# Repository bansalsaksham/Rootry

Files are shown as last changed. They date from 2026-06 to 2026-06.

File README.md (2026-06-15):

# Rootry (formerly SoilHawk) | Automatic Irrigation System

An evolving hardware IoT project focused on providing low-cost, high-efficiency, solar-powered precision irrigation for smallholder farms in India. What began as an award-winning science exhibition prototype has evolved into a field-tested product architecture achieving significant water conservation.

**Key Achievements:**
* 🏆 **Runner-up (2nd Worldwide):** UPenn EcoVenture Global Climate Venture Competition (2024)
Saksham Certificate_page-0001

* 🏆 **Winner:** CBSE National Science Exhibition (2019) & Regional Science Exhibition (2018-19)
* 🌟 **Government Recognition:** Recommended as *Jal Doot* by the Ministry of Jal Shakti

---

## 🚀 The Product Evolution

This project has undergone several architectural iterations, moving from a basic microcontroller logic proof-of-concept to a distributed ML concept, and finally to a robust, custom ESP32 IoT system.

### Phase 3: Rootry v2 (Current Architecture - 2024 to Present)
The current iteration focuses on productization, robustness, and real-world deployment constraints. Designed for areas with limited grid power and no smartphone access, keeping the unit cost under ₹4,000.

* **Verified Impact:** Field-tested across a 4-acre site, achieving a **30% reduction** in water usage (250 L/m² vs control of 360 L/m²).
* **Hardware Stack:** * Custom PCB designed in **KiCad**.
  * **MCU:** ESP32-S3 (Dual-core 240MHz) replacing the legacy Arduino architecture.
  * **Connectivity:** Hybrid Dual GSM (SIM800L via UART AT commands) + WiFi interface.
  * **Power:** 10W Solar Panel + 12V SLA Battery with PWM charge controller.
* **Firmware Improvements:**
  * Replaced all legacy `delay()` calls with non-blocking loops using `millis()`.
  * Implemented **Hysteresis Band Control**: Pump turns ON below 30% moisture and OFF above 50% to prevent rapid toggling.
  * **Adaptive Temperature Compensation:** Stop thresholds dynamically raise to 60% when ambient temperatures exceed 35°C (read via DHT22).
  * **Web Dashboard:** `ESPAsyncWebServer` integration for a real-time localized dashboard.

---

### Phase 2: SoilHawk (2023 - ImpactHack Sponsor Track Winner)
A conceptual expansion into a distributed, multi-node architecture utilizing both ground-based sensing and aerial diagnostic telemetry. This phase validated the integration of machine learning for targeted agricultural interventions.

Add your next level pages (1)

---

### Phase 1: The Foundation (2019 Prototype)
The genesis of the project. A standalone prototype built to demonstrate the core viability of automated soil moisture management to prevent soil degradation and conserve water. 

* **The Setup:** Arduino Uno, FC-28 Soil Moisture Sensor, DHT11 Temperature/Humidity Sensor, 16x2 LCD, 5V Relay for water pump actuation, and a basic GSM module.
* **Logic:** Basic linear logic. The system reads analog moisture thresholds. If the soil falls below `MAXDRYNESS 600`, the pump is triggered, and the GSM module dispatches an SMS alert ("Motor Start") to the farmer.
* **Validation:** Documented in a formal research paper analyzing the mathematical and environmental impact, endorsed by Dr. Sumeet Gill, Professor of Computer Science at MDU Rohtak.



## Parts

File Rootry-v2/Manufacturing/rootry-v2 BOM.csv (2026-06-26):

Id | Designator | Footprint | Quantity | Designation | Supplier and ref
1 | D3 | D_DO-41_SOD81_P10.16mm_Horizontal | 1 | 1N5817
2 | C9,C8,C4,C3,C5,C6 | C_Disc_D5.0mm_W2.5mm_P5.00mm | 6 | 100nF
3 | K1 | Relay_SPDT_Omron_G5V-1 | 1 | G5V-1-12VDC
4 | J5,J6 | TerminalBlock_MaiXu_MX126-5.0-02P_1x02_P5.00mm | 2 | Conn_01x02
5 | R9,R7 | R_Axial_DIN0207_L6.3mm_D2.5mm_P10.16mm_Horizontal | 2 | 4.7k
6 | U2 | SOT-223-3_TabPin2 | 1 | AMS1117-3.3
7 | J2-DHT22,J1-SOIL1 | PinHeader_1x03_P2.54mm_Vertical | 2 | Conn_01x03
8 | C10,C7 | CP_Radial_D10.0mm_P5.00mm | 2 | 1000uF
9 | C11 | CP_Radial_D6.3mm_P2.50mm | 1 | 100uF
10 | D2 | LED_D5.0mm | 1 | LED
11 | R1,R3,R5,R4 | R_Axial_DIN0207_L6.3mm_D2.5mm_P10.16mm_Horizontal | 4 | 10k
12 | Q1 | TO-92_Inline | 1 | BC547
13 | U1 | ESP32-S3-WROOM-1 | 1 | ESP32-S3-WROOM-1
14 | J4-SIM80L1,J3-LCD1 | PinHeader_1x04_P2.54mm_Vertical | 2 | Conn_01x04
15 | C1,C2 | CP_Radial_D5.0mm_P2.50mm | 2 | 10uF
16 | SW2 | SW_PUSH_6mm_H5mm | 1 | BOOT
17 | R6 | R_Axial_DIN0207_L6.3mm_D2.5mm_P10.16mm_Horizontal | 1 | 4.7K
18 | SW1 | SW_PUSH_6mm_H5mm | 1 | RESET
19 | R2 | R_Axial_DIN0207_L6.3mm_D2.5mm_P10.16mm_Horizontal | 1 | 1k
20 | D1 | D_DO-41_SOD81_P10.16mm_Horizontal | 1 | 1N4007
21 | R10 | R_Axial_DIN0207_L6.3mm_D2.5mm_P10.16mm_Horizontal | 1 | 220

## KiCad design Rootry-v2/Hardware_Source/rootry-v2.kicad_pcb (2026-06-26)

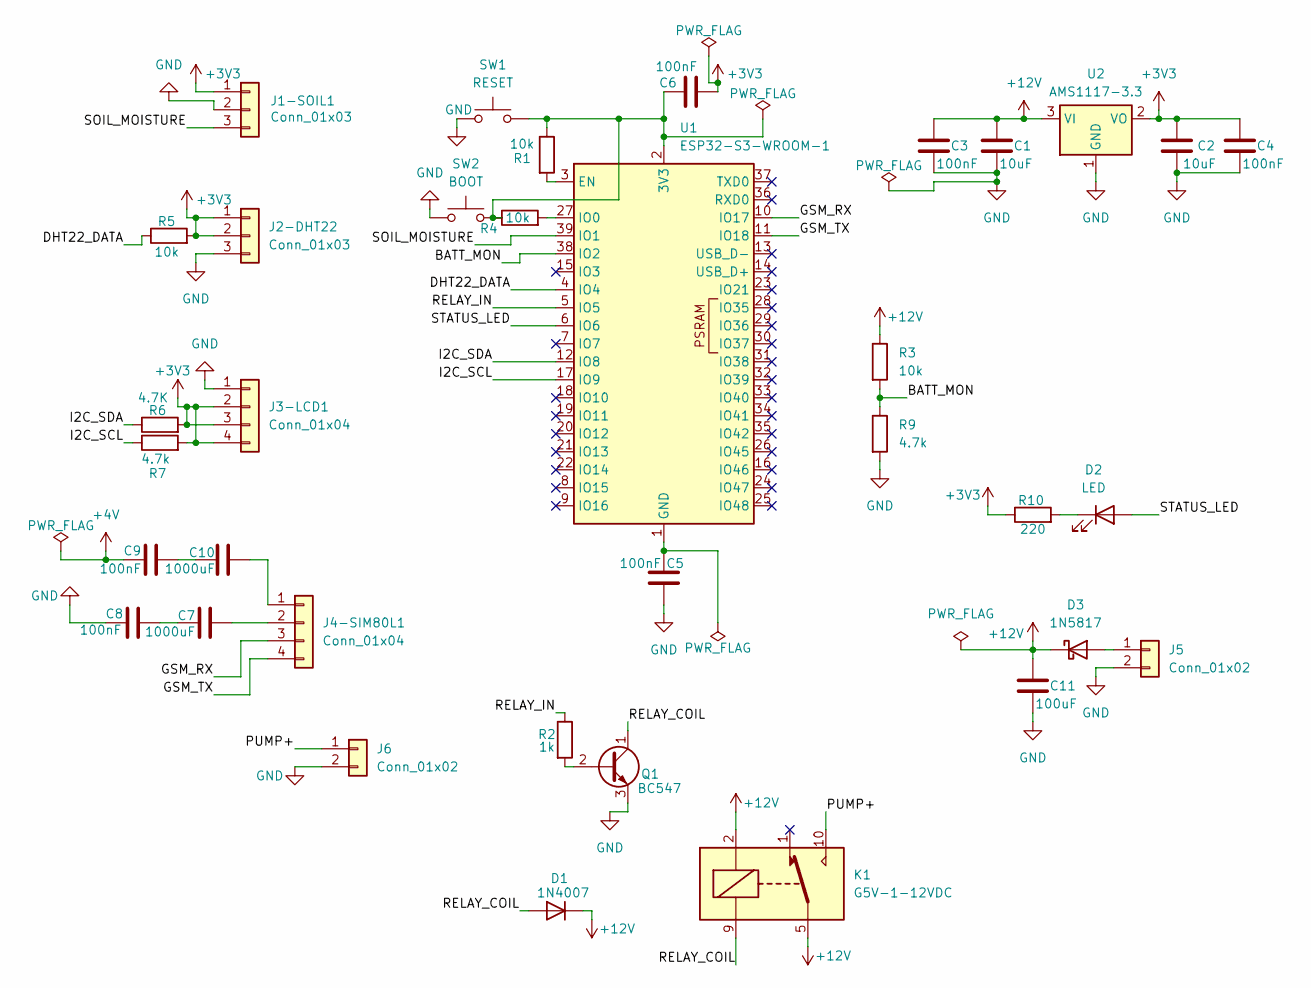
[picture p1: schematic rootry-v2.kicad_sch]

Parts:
C1, C2: 10uF; CP_Radial_D5.0mm_P2.50mm
C3, C4, C5, C6, C8, C9: 100nF; C_Disc_D5.0mm_W2.5mm_P5.00mm
C7, C10: 1000uF; CP_Radial_D10.0mm_P5.00mm
C11: 100uF; CP_Radial_D6.3mm_P2.50mm
D1: 1N4007; D_DO-41_SOD81_P10.16mm_Horizontal
D2: LED; LED_D5.0mm
D3: 1N5817; D_DO-41_SOD81_P10.16mm_Horizontal
J1-SOIL1, J2-DHT22: Conn_01x03; PinHeader_1x03_P2.54mm_Vertical
J3-LCD1, J4-SIM80L1: Conn_01x04; PinHeader_1x04_P2.54mm_Vertical
J5, J6: Conn_01x02; TerminalBlock_MaiXu_MX126-5.0-02P_1x02_P5.00mm
K1: G5V-1-12VDC; Relay_SPDT_Omron_G5V-1
Q1: BC547; TO-92_Inline
R1, R3, R4, R5: 10k; R_Axial_DIN0207_L6.3mm_D2.5mm_P10.16mm_Horizontal
R2: 1k; R_Axial_DIN0207_L6.3mm_D2.5mm_P10.16mm_Horizontal
R6: 4.7K; R_Axial_DIN0207_L6.3mm_D2.5mm_P10.16mm_Horizontal
R7, R9: 4.7k; R_Axial_DIN0207_L6.3mm_D2.5mm_P10.16mm_Horizontal
R10: 220; R_Axial_DIN0207_L6.3mm_D2.5mm_P10.16mm_Horizontal
SW1: RESET; SW_PUSH_6mm_H5mm
SW2: BOOT; SW_PUSH_6mm_H5mm
U1: ESP32-S3-WROOM-1
U2: AMS1117-3.3; SOT-223-3_TabPin2

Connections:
+3V3: C2.1, C4.1, C6.1, J1-SOIL1.1, J2-DHT22.1, J2-DHT22.2, J3-LCD1.2, J3-LCD1.3, J3-LCD1.4, R5.2, R6.2, R7.2, R10.1, U2.2 (VO)
+4V: C9.1
+12V: C1.1, C3.1, C11.1, D1.1 (K), D3.1 (K), K1.2, K1.5, K1.6, R3.1, U2.3 (VI)
/BATT_MON: R3.2, R9.1, U1.38 (IO2)
/DHT22_DATA: R5.1, U1.4 (IO4)
/GSM_RX: J4-SIM80L1.3, U1.10 (IO17)
/GSM_TX: J4-SIM80L1.4, U1.11 (IO18)
/I2C_SCL: R7.1, U1.17 (IO9)
/I2C_SDA: R6.1, U1.12 (IO8)
/PUMP+: J6.1, K1.10
/RELAY_COIL: D1.2 (A), K1.9, Q1.1 (C)
/RELAY_IN: R2.1, U1.5 (IO5)
/SOIL_MOISTURE: J1-SOIL1.3, U1.39 (IO1)
/STATUS_LED: D2.2 (A), U1.6 (IO6)
GND: C1.2, C2.2, C3.2, C4.2, C5.1, C8.1, C11.2, J1-SOIL1.2, J2-DHT22.3, J3-LCD1.1, J5.2, J6.2, Q1.3 (E), R9.2, SW1.1, SW2.1, U2.1 (GND)
unnamed: C5.2, U1.1 (GND), U1.40 (GND), U1.41 (GND)
unnamed: C7.1, C8.2
unnamed: C9.2, C10.1
unnamed: D2.1 (K), R10.2
unnamed: D3.2 (A), J5.1
unnamed: C10.2, J4-SIM80L1.1
unnamed: C7.2, J4-SIM80L1.2
unnamed: Q1.2 (B), R2.2
unnamed: C6.2, R1.1, R4.1, SW1.2, SW2.2, U1.2 (3V3)
unnamed: R1.2, U1.3 (EN)
unnamed: R4.2, U1.27 (IO0)

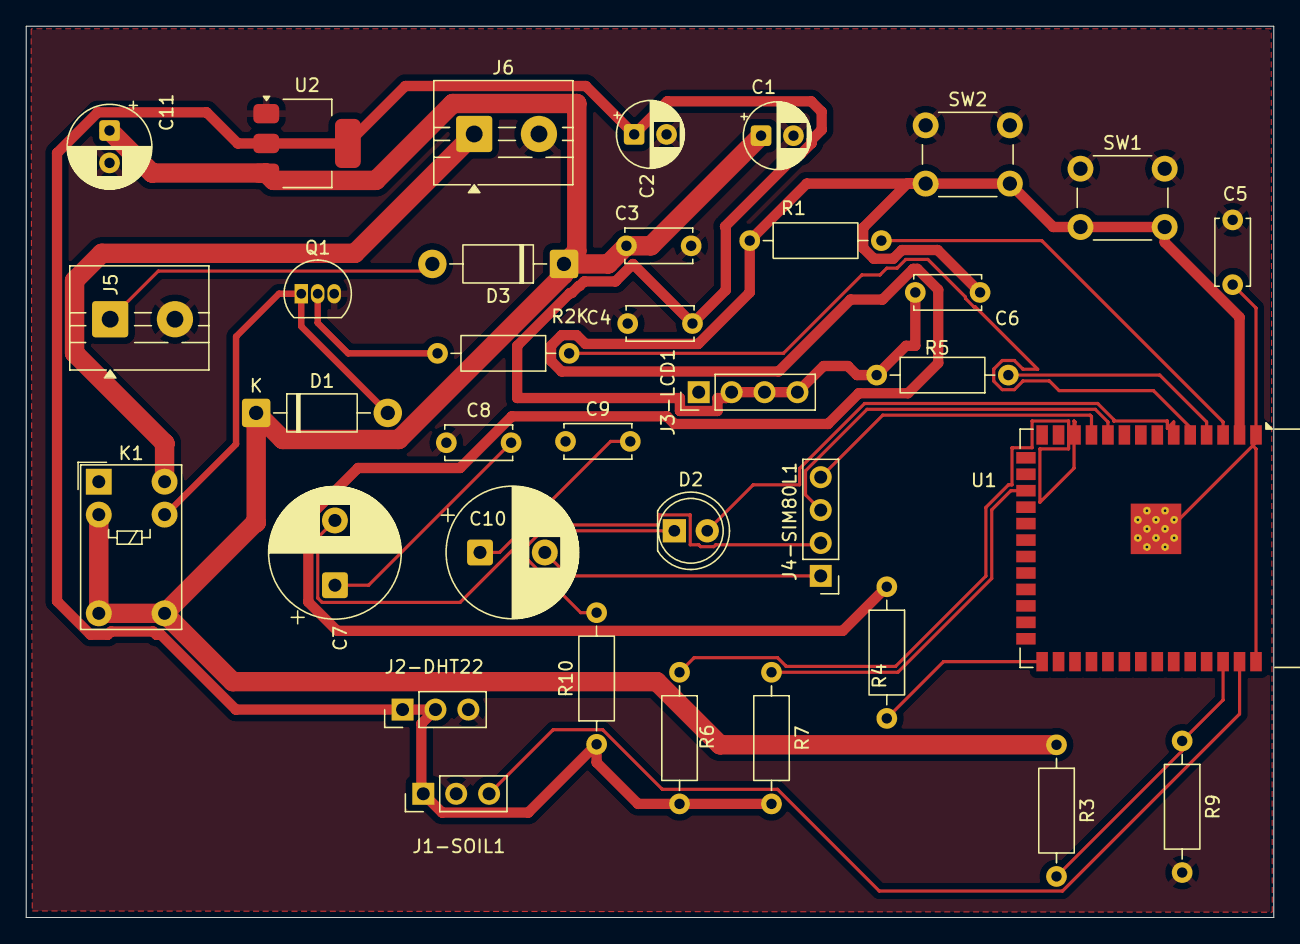
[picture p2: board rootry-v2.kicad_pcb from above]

Board: 2 copper layers, 96.3 x 68.8 mm, 35 parts (0 on the bottom side), 25 nets.
